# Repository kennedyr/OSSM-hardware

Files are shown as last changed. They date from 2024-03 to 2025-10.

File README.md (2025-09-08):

# OSSM - Open Source Sex Machine

OSSM Overview Image

### [**KinkyMakers Discord Community**](https://discord.gg/VtZcudpxT6) 
  
Most OSSM development takes place through ideas and CAD contributions made by enthusiastic discord members, join the discussion or show off your build!  

### Check out our docs at [GitBook](https://kinky-makers.gitbook.io/)

### [**Read the Frequently Asked Questions**](FAQ.md)

## **Summary**   
**OSSM** (pronounced like "awesome") is a user friendly every day sex machine for the people.

The OSSM's primary feature is that it is a servo powered belt-driven linear rail.  
This allows for quiet, high torque operation at speeds up to 1 meter per second, as well as for software-defined stroke and depth. 

**Standard Recommended Build at a glance**
 - 32 lbs (14 kg) of force @ 20v DC
   - Up to 50 lbs (22 kg) @ 36v DC
 - 8" Stroke (20 cm) with 350mm rail

This project aims to help people curious about sex machines explore their interest.   
A second objective is optionally learning how mechanics, electronics, physics and computing are involved in your sexual pleasure.

### **Primary** Design Goals
- Compact & quiet
- Highly performant
- Moderate cost
- 3D printable
- Easily-sourced components
- Moddable
  
<p align="center">

</p>

Note: This is a _work in progress_ and we have attempted to keep compatibility with the current BOM going
forward, but it's not guaranteed.

### Is it *actually* Open Source?
    CERN Open Hardware Licence Version 2 - Strongly Reciprocal
It is one of a kind Certified, Actual, Factual, Open Source  
[](https://certification.oshwa.org/ca000057.html)

Contributions to this GitHub repository assume the same license.

## **Safety**

The safety of the OSSM is yet to be fully characterized as it is a work in progress.  
The OSSM is a framework for building your own sex machine and as such your specific combination may have risks not inherent to other builds.  
**These risks may be undocumented or undiscovered. Please see the [Hazards](Documentation/Hazards.md) file for more information.**

Use of experimental/modified code increases the level of risk.

While using the OSSM we can suggest the following hierarchy of safety, however it is up to you and your build to decide
what risks exist and how to mitigate them.

1. Have ability to move away
2. Have ability to remove the power
3. If you are in bondage, safety is responsibility of the Top

## **Building Your OSSM**
### Motor Support  
 - 57AIM30 "Gold Motor" (Standard Recommended)
 - 42AIM30 "Round Motor" (Smaller form factor, limited mounting support)
 - iHSV57 "Legacy Motor" (Pre-2024 recommended motor)

The OSSM Software is written to support closed loop servo type motors and tested on the above motors.  
Most OSSM actuator and mounting hardware is designed for NEMA23 form factor motors.  
Attempting to use a stepper or other motor is not recommended; while it may be technically possible in some cases, this usually requires custom design work and advanced-level custom code. 

### Bill Of Materials for Standard Recommended Build

### Electronics  

 - Motor 
   - 57AIM30 ["Gold Motor"](https://www.researchanddesire.com/products/ossm-motor-gold-motor)
     - **Important note:** In order to operate with OSSM Software, motors must receive programming to set their "steps per revolution" to 800.
     - Motors from R+D are pre-programmed for OSSM. Motors from all other sources will need programming.
     - Programming requires a USB to 4 pin RS485 connector, cable for the 8 pin white motor plug, and use of the [Gold Motor Programming Tool](/Hardware/Servo%20Tools/Gold%20Motor/)
 - OSSM Reference Board, Remote, Wiring
    - [OSSM Reference PCB](https://www.researchanddesire.com/products/ossm-reference-board) or ESP32 Development Board
      - More information for board development [here](/Documentation/Board_Design.md).
    - [OSSM Remote](https://www.researchanddesire.com/products/ossm-reference-board)
    - JST-PH 2.0 4-Pin data cable and 16awg power wire
      - [Wire harness - Gold Motor](https://www.researchanddesire.com/products/ossm-wire-harness-gold-motor)
 - 20-36v DC Power Supply (5.5 x 2.1 Barrel Plug)
   - [24 volt 5 amp](https://www.researchanddesire.com/products/ossm-24v-power-supply) is recommended
   - Higher voltage, up to 36v, will provide increased force
   - USB Power Banks capable of true 100w USB PD also generally seem to operate well for a portable OSSM
     - [TESTED: ✓] INIU Power Bank P63-E1 100w (Old model: B63)
     - [TESTED: Powers down on high load] INIU B62 Power Bank 65W

### [**Printed Parts**](Printed%20Parts/) 
 - [Actuator](Printed%20Parts/Actuator/)
   - Body
   - Belt Tensioner
   - Threaded End Effector, Clamp + Nut  
 - [Remote](Printed%20Parts/Remote/)
   - Body
   - Knobs
 - [Toy Mounting](Printed%20Parts/Toy%20Mounting/)
   - Flange Base Plate with Clamping Ring (Tie-Down or Suction)
   - Double Double (Vac-U-Lock)
 - [Mounting](Printed%20Parts/Mounting/)
   - Mounting Ring (PitClamp Mini Ring)
   - Base (PitClamp Mini Base)
   - PCB Enclosure
 - [Stand](Printed%20Parts/Stand/)
   - 3030 Extrusion Base

Experimental parts pop up in the [KinkyMakers Discord](https://discord.gg/wrENMKb3) #ossm-print-testing channel.  
W.I.P. for the top rated to be merged into this repo.

### Standard Actuator Hardware
**GT2 Pulley** 

    (Qty 1) 8mm Bore, 20 Tooth, 10mm Width
**GT2 Timing Belt** 

    (Qty 1) 10mm Width, 500mm length
**MGN12H Rail + Bearing Block**

    (Qty 1)
    Minimum 250mm
    Suggested 350mm
    Maximum 550mm

Rail length = desired maximum stroke + 180mm  
Must be MGN**12H** rail.  
H is a longer bearing block than C for greater stability. 12 indicates 12mm rail width.

**Ball Bearings**

    (Qty 6) MR115-2RS 5x11x4mm 

**Fasteners**  

    (Qty 8) M3x8  Socket Cap Head Bolt 
    (Qty 2) M3x16 Socket Cap Head Bolt 
    (Qty 1) M3x20 Socket Cap Head Bolt 
    (Qty 7) M3 Hex Nut
    (Qty 3) M5x20 Socket Cap Head Bolt
    (Qty 1) M5 Hex Nut
    (Qty 4) M5x35 Socket Cap Head Bolt 
    (Qty 4) M5 20mm Hex Coupling Nut (Or M5 Hex Nut)

**Additional hardware is required for Stand, Mounting, Remote  
Detailed in their respective [Printed Parts](Printed%20Parts/) folder**

## Assembly

**Important note:** The actuator rail direction is critical for pattern accuracy and safety functions. The proper direction is with the threaded end to the right when looking at the front face of the actuator body - the "M" side of the OSSM text on the Cover.  
Outdated videos and documentation may show different directions. Your rail should extend the threaded end first when booted; if this does not match the behavior of your build you should reverse your rail's printed hardware.

  
### [**Build Instructions**](Documentation/Assembly%20Instructions.pdf)
(03.30.2025) Note: There have been recent improvements to the OSSM Standard Recommended build that are not yet reflected in this build document.  
Refer to exploded views from the Printed Parts folders for assembly of each major component.
## Build Videos

[OSSM Assembly Playlist](https://youtube.com/playlist?list=PLzSK7OAu3KNQsFo6WJGT8P28lfkD3xpps)

[OSSM Complete Assembly - Follow Along Guide](https://www.youtube.com/watch?v=9lVobSEw_Uw)

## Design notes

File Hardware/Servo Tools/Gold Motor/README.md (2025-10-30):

<h1> New Web Serial tool </h1>

Note programming an AIM motor requires not only power for the RS485, the motor needs between 20-40v otherwise it will not communicate. Look for the green light on the rear of the servo.  

in the "Javascript GMP" folder run the page in some browser that supports web serial and hopefully it'll just work. 



<h1> Old Python Script </h1>
This pyhton script will write the default changes to the gold motor and show all the current settings in mostly english



the settings we change by default are



Watch out, I got tired of using the tool provided by the vendor and this was done quickly one night with ChatGPT as my copilot...

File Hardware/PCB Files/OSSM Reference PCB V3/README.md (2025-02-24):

# OSSM V3 Board info

## V3 Changes

1. ESP32 -> ESP32-S3
2. Current monitor is changed from an analog monitor to an in-line resistor and the INA219.

## Beta 1 testing

1. Motor motion
    1. The U8g2 library doesn't play nice with other devices on the I2C bus. There are a few different things happening here.  First, the bus maxes out the clock speed per the display.  Second the code doesn't want to play nice with the buffers
1. General Connections
    1. The Encoder wheel's A/B lines are swapped. (Or somehow the encoder works backwards)
1. RS485 works-ish.
    1. Packets are being sent and recieved, but the motor is responding with a function code that isn't listed.
    1. The RE/DE pins should be shorted in HW.  (Probably using a solder jumper)
1. Neopixel Works with the FastLED library.
1. TODO: HUSB238 I2C connection. Not critical to check, but should be moved with INA219

### Beta1 -> RC1 Changes

1. Move display to it's own I2C periphal.
1. Change HUSB28 to HUSB238A.  It is available on LCSC and will allow higher power.
    1. Double check all components to handle max voltage.  Should that be 36V (Gold motor max) or 48V (IC max)
1. Make the programmable LED smaller
1. Swap Encoder A/B pins
1. Short the DE and RE pins
1. Shrink Q1&Q2
1. Pick final connectors for Motor connection (both power/pulse/dir and RS85)
1. Pick connector for remote
1. Change PCB form factor

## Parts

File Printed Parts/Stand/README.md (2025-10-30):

### Default base: [3030 Extrusion - Single Pivot Arm](#ossm---3030-extrusion-mount)

# OSSM - 3030 Extrusion Mount

<!-- ### [Bill Of Materials](3030%20Extrusion%20Base/BOM.md)   -->

### [Assembly Guide Videos](https://www.youtube.com/playlist?list=PLzSK7OAu3KNS-aOQfpv3f_BJH9GNdLJ7Q)

### Printing

**3030 Extrusion Mount Standard Print Settings:**

    6 Walls
    Infill type: Cross Hatch (or gyroid) 25%
    Supports: None

- **Filament estimate:** 246g
- **Recommended filament:** PLA+
- All parts are intended to print in the provided file default orientation.

**Printed parts:**

    (Qty 1) Pivot Plate Left
    (Qty 1) Pivot Plate Right
    (Qty 8) Handle Spacer
    (Qty 4) Extrusion Foot
    (Qty 6) Extrusion Cap

<!-- ### [Additional Documentation](3030%20Extrusion%20Base/README.md)  -->

### Bill Of Materials

    (Qty 12) M6x12 Socket Cap Head Bolt
    (Qty  6) M6x25 Socket Cap Head Bolt
    (Qty  2) M6 Handle 25mm
    (Qty  6) M6 Washer
    (Qty 20) M6 T-Nut '3030'
    (Qty  4) 90 Degree '3030' Corner Bracket
    (Qty  2) 1.5" (38mm) Reinforced Rubber Washer
    (Qty  4) 1.5" (38mm) Square Non-Slip Furniture Pad
    (Qty  1) 20" (508mm) 3030 Extrusion
    (Qty  1) 18" (467mm) 3030 Extrusion
    (Qty  2) 14" (355mm) 3030 Extrusion
    (Recommended) Sandbag

## Legacy README

The above BOM is accurate for a new Stand-only assembly. Actuator and PCB Mounting BOM can be found in [Mounting](/Printed%20Parts/Mounting/)

Legacy README retained for Stand assembly reference

    //TODO: Needs update for 57AIM30 Gold Motor & PitClamp Mini default build.

You can view the 3D model at
[OnShape link](https://cad.onshape.com/documents/d520ea9a8cadb4ae8681f59b/w/00b211a6fa3b76c59ef28f4e/e/5f2c80d9d9c2433a7be7f789)



<!-- ![image](https://github.com/KinkyMakers/OSSM-hardware/assets/12459679/68e3e564-df99-465a-8d91-f74ca8b0cc89) -->



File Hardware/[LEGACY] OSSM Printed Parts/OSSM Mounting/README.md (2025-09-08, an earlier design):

# Mounting Options

There are several options for mounting your OSSM! You will find descriptions of the mounts below, and the files and instructions on how to build them in the folders above. 

The **OSSM Basic Mount** is the "official" design and is available to [purchase from Research and Desire](https://shop.researchanddesire.com/collections/all/products/ossm-basic-mount). It is mostly 3D printed and is screwed down to a piece of wood, furniture, shelf etc. It uses the 3D printed middle pivot and threaded handles. Current design relies on sourcing a length of 3030 extrusion (1.5" will also work). This is one of the less expensive options. Picture below.

rdmount

The **Shicks 4040 mount** was created by discord community member Shicks101 (Thanks!) and is made out of Aluminum Extrusion and 3D printed parts. It supports a high level of articulation and variability in height. The parts are easy to get, but it is a little more costly. You may need to weigh it down with dumbbells or sandbags. Picture below.

resized

The **OSSM Extrusion Mount** is an extrusion based mount that is simple to print and assemble requiring no cutting tools if you can get extrusion at the correct length. It uses the standard middle pivot and only a few 3D printed pieces.


**Emma's mod** is for the use of a long Nema23. This mount is mostly 3D printed and was created for a different machine, but will still work. (no photo available)  

There are a few more mounting options created by community members in the Discord that are not present here in the repository. Some are motorized! Or if none of these fit your use case, you could create your own and share it with the community.

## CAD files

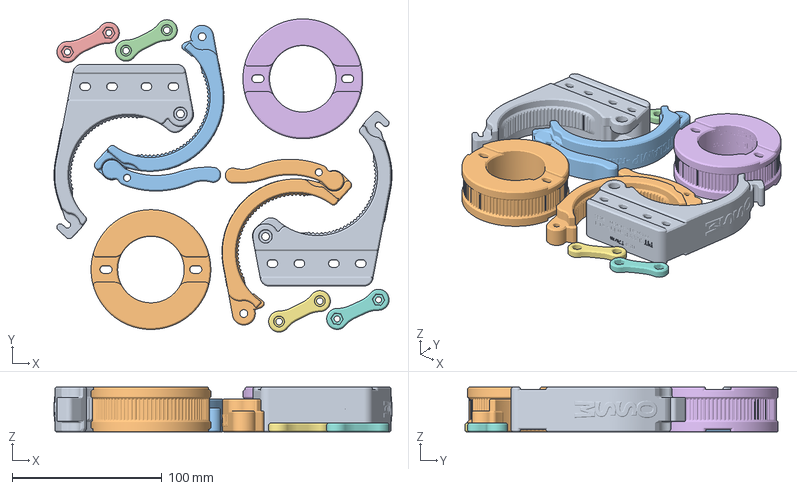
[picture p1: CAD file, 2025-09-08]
Printed Parts/OSSM Mods/PitClamp Mini Reinforced 3030 Hinges/Preconfigured 3mf/[Generic_3mf] 2x - PitClamp Mini v1.1 - Reinforced 3030 Hinge Complete.3mf
225.9 x 209.2 x 30.0 mm
OSSM - Base - PitClamp Mini - Lower V1.1 - Reinforced SideMount 3030.stl x 2
OSSM - Mounting Ring - PitClamp Mini - Extrusion Reinforced.stl x 2
OSSM - Base - PitClamp Mini - Upper V1.1 + Handle (Print In Place).stp x 2
OSSM - Base - PitClamp Mini - Dogbone Bolts.stp x 2
OSSM - Base - PitClamp Mini - Dogbone Nuts.stp x 2

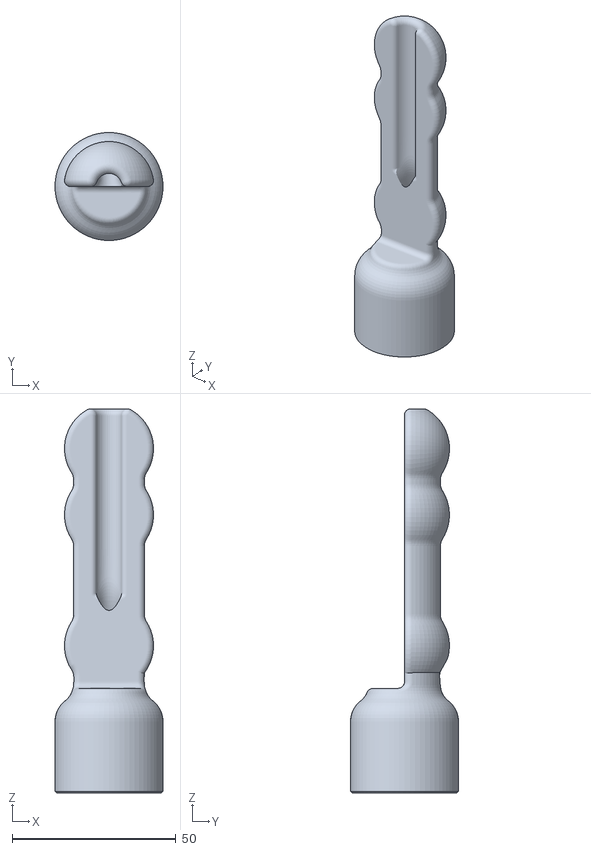
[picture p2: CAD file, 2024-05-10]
Hardware/OSSM Printed Parts/end effector options/Silly/OSSM hold random object on 24mm thread.stl
33.0 x 33.0 x 117.4

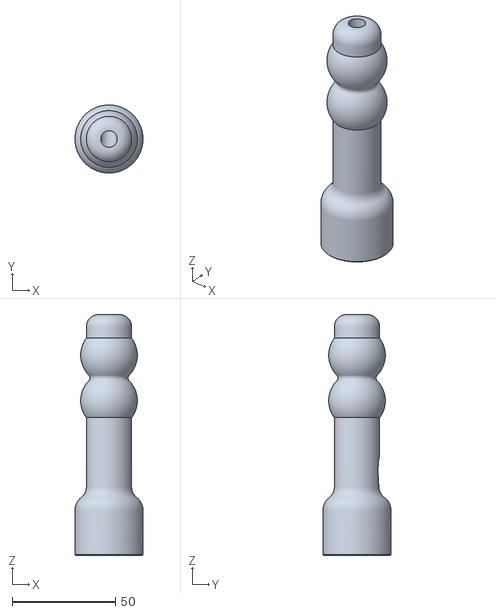
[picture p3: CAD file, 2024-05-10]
Hardware/OSSM Printed Parts/OSSM - Toy mount - Dildo mount Double Double (vac-u-loc)- 24mm threaded.stl
33.0 x 33.0 x 116.8

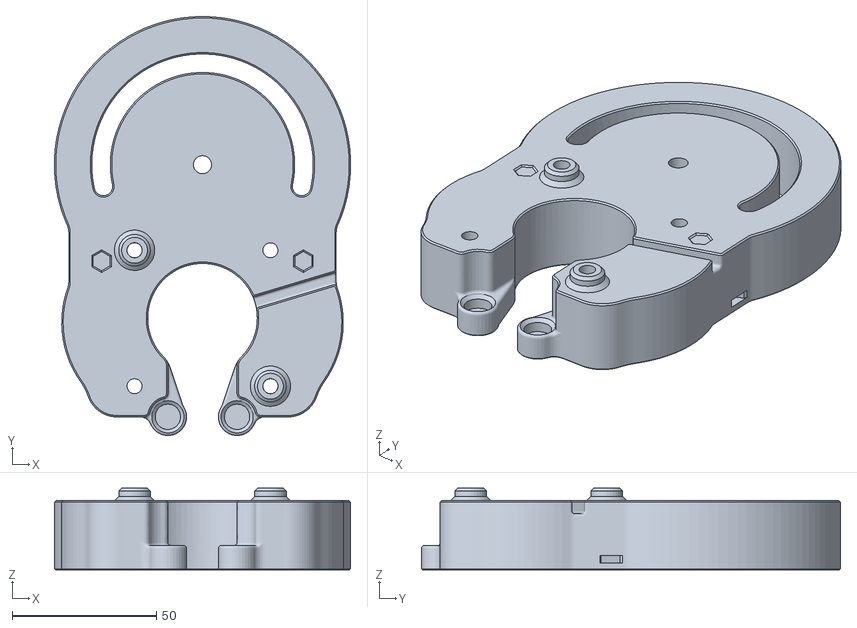
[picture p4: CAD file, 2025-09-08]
Printed Parts/Actuator/Non-standard/OSSM - Actuator - Body - Middle Pivot.stl
102.8 x 145.3 x 28.4

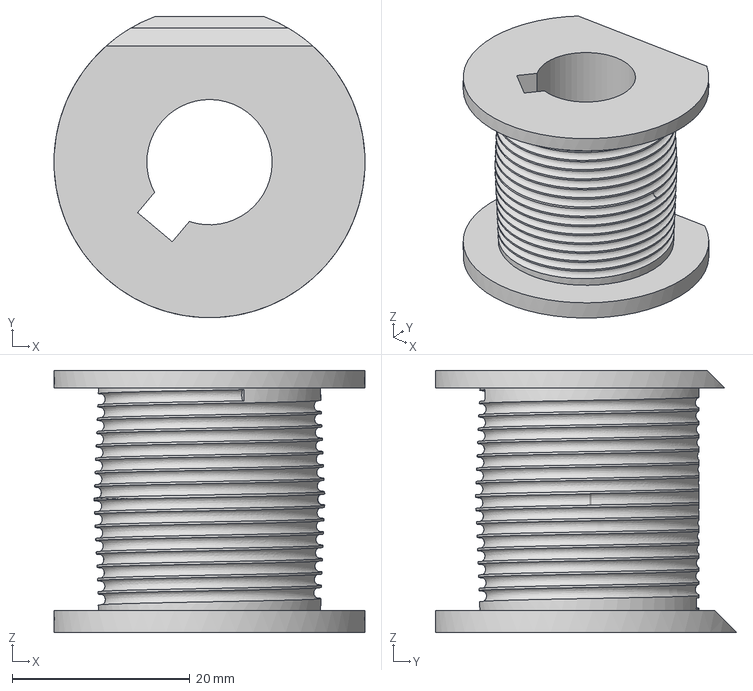
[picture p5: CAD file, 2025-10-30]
Printed Parts/OSSM Mods/SaladDressing's Mods/Capstan OSSM XL/Hardware/.step/CapstanPulley60AIM25.step
35.0 x 33.9 x 29.5 mm

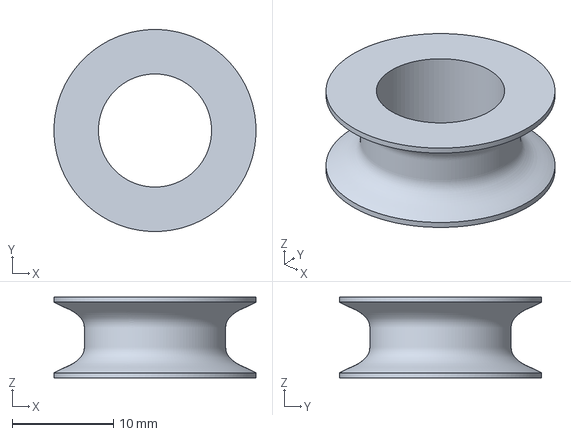
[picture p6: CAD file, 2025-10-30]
Printed Parts/OSSM Mods/SaladDressing's Mods/Capstan OSSM XL/Hardware/3D printed parts/8mmEndPulley.3mf
20.0 x 20.0 x 8.00 mm

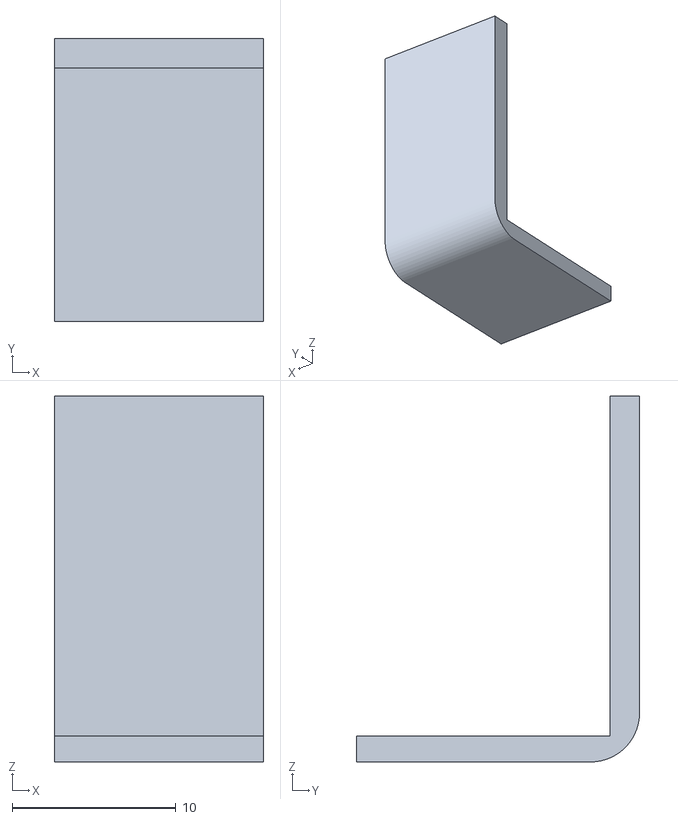
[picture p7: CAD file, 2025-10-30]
Printed Parts/OSSM Mods/SaladDressing's Mods/Capstan OSSM XL/Hardware/3D printed parts/AIO Mod (recommended)/Standoff2.stl
12.8 x 17.3 x 22.4

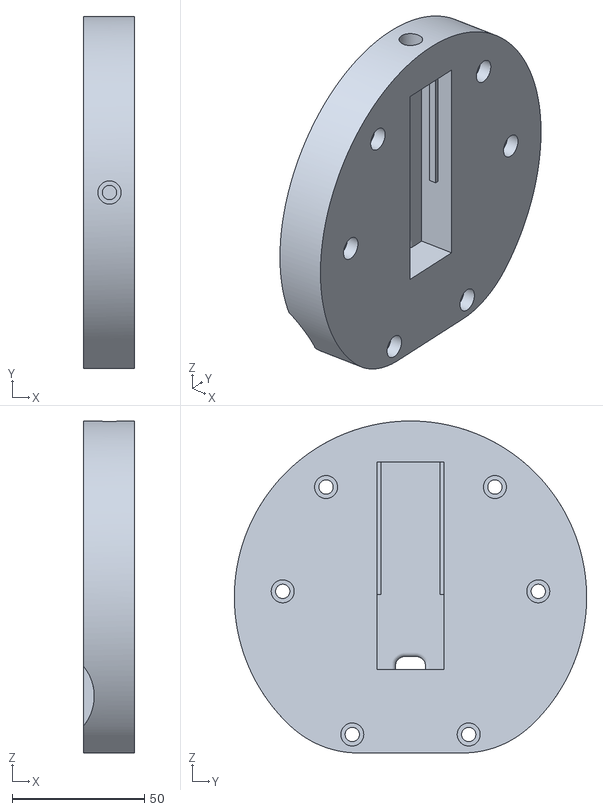
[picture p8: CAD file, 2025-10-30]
Printed Parts/OSSM Mods/SaladDressing's Mods/Capstan OSSM XL/Hardware/3D printed parts/Normal (for customized PCB Mounting)/MotorHeadFront.stl
19.1 x 133.1 x 125.5

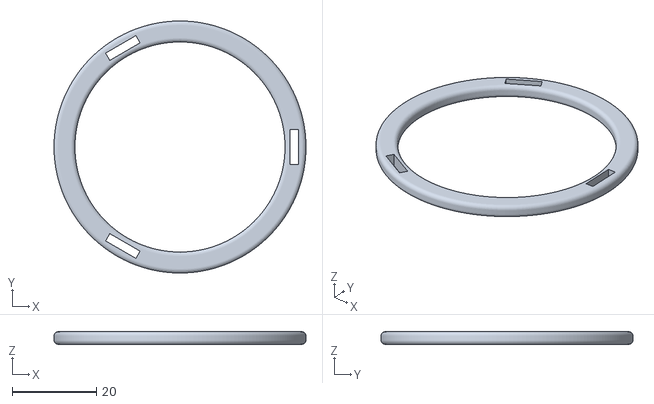
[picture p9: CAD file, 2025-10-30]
Printed Parts/OSSM Mods/SaladDressing's Mods/Quick Change Strap Toy Mount Remix/Ring50mm.stl
60.0 x 60.0 x 3.00

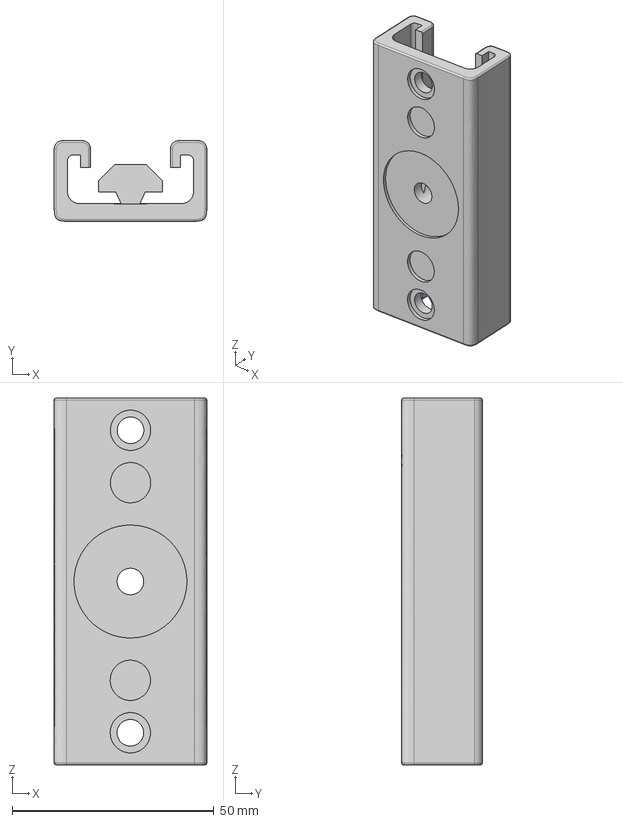
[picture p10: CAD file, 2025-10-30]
Printed Parts/OSSM Mods/SaladDressing's Mods/Suction Cup Bracket/SuctionCupBracket - 3030 Amazon by neos.step
37.8 x 20.0 x 91.0 mm

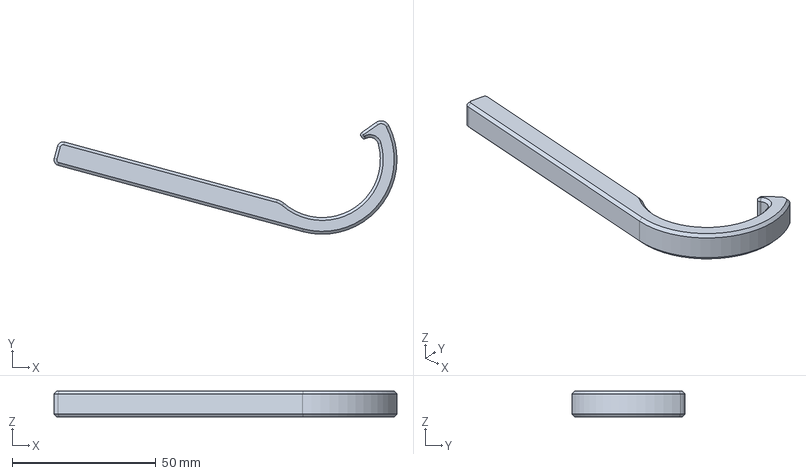
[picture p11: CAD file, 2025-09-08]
Printed Parts/OSSM Mods/Threaded Belt Clamp V2/STEP/Tool - Hex Flower Wrench.stp
119.2 x 39.4 x 9.00 mm

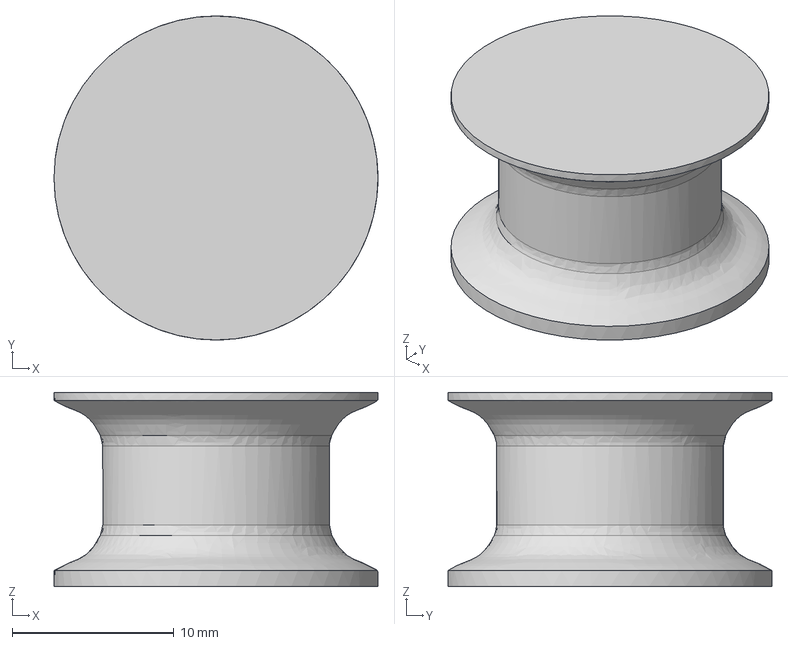
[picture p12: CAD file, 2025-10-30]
Printed Parts/OSSM Mods/SaladDressing's Mods/Capstan OSSM XL/Hardware/.step/EndPulley12mm.step
20.0 x 20.0 x 12.0 mm

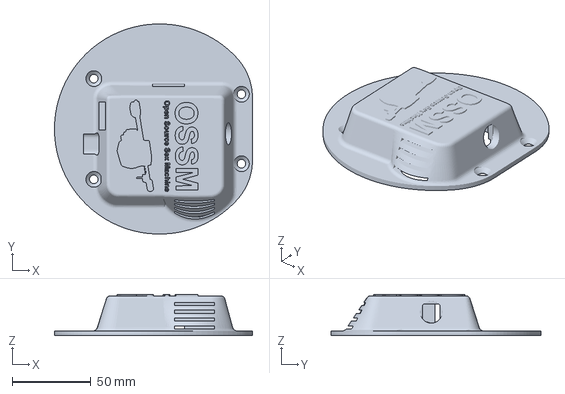
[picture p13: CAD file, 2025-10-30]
Printed Parts/OSSM Mods/SaladDressing's Mods/Capstan OSSM XL/Hardware/3D printed parts/AIO Mod (recommended)/AIO_Cover.3mf
125.4 x 133.1 x 26.2 mm

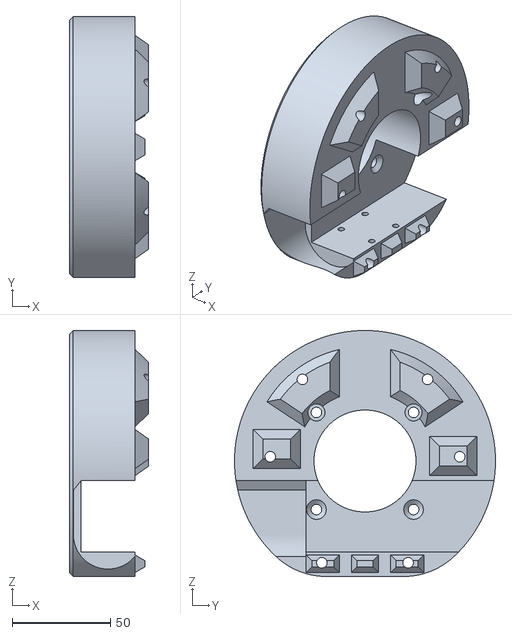
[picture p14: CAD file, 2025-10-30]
Printed Parts/OSSM Mods/SaladDressing's Mods/Capstan OSSM XL/Hardware/3D printed parts/Normal (for customized PCB Mounting)/MotorHeadBack.stl
40.5 x 133.1 x 125.5

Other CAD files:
Printed Parts/OSSM Mods/SaladDressing's Mods/Capstan OSSM XL/Hardware/3D printed parts/TensionerLower.stl
Printed Parts/OSSM Mods/SaladDressing's Mods/Quick Change Strap Toy Mount Remix/universal_strap_3mm_notch.stl
Printed Parts/OSSM Mods/SaladDressing's Mods/Suction Cup Bracket/SuctionCupBracket - 4040 Aluxprofile.step
Printed Parts/OSSM Mods/SaladDressing's Mods/Weight Plate Bracket/Weight Plate Bracket Olympic.step
Hardware/[LEGACY] OSSM Printed Parts/OSSM Mounting/Deprecated - Ball Head Mount/Fusion Files/Adjustable arm for ball head mount v2.f3d
Hardware/[LEGACY] OSSM Printed Parts/OSSM Mounting/Deprecated - Ball Head Mount/STL Files/Extension arm for ball head.stl
Hardware/[LEGACY] OSSM Printed Parts/OSSM Mounting/Deprecated - Ball Head Mount/STL Files/Mounting base left side.stl
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

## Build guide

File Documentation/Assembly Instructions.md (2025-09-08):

# Assembly Instructions

#### _Note: This file is a work in progress migration of legacy documentation and may contain outdated information or parts_

## Open Source Sex Machine

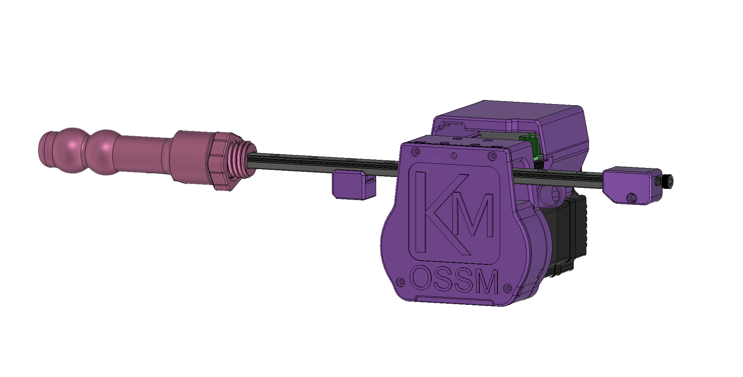
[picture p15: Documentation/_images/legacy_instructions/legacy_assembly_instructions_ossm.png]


Assembly Guide

### Table of Contents

* [Some comments on Safety](<Assembly Instructions.md#some-comments-on-safety>)
* [Parts Checklist](<Assembly Instructions.md#parts-checklist>)
  * [Purchased Parts](<Assembly Instructions.md#purchased-parts>)
  * [Printed Parts](<Assembly Instructions.md#printed-parts>)
* [Assembly Instructions](<Assembly Instructions.md#assembly-instructions>)
  * [Mate the Base Plate with the Motor](<Assembly Instructions.md#mate-the-base-plate-with-the-motor>)
  * [Build up the belt idler bearings](<Assembly Instructions.md#build-up-the-belt-idler-bearings>)
  * [Install and Align the Pulley](<Assembly Instructions.md#install-and-align-the-pulley>)
  * [Linear Rail Installation](<Assembly Instructions.md#linear-rail-installation>)
  * [Alternate Middle – Pivot](<Assembly Instructions.md#alternate-middle--pivot>)
  * [Belt Placement](<Assembly Instructions.md#belt-placement>)
  * [Belt Tensioner](<Assembly Instructions.md#belt-tensioner>)
  * [Wrap Belt Around Pulley](<Assembly Instructions.md#wrap-belt-around-pulley>)
  * [Belt Clamp](<Assembly Instructions.md#belt-clamp>)

## Some comments on Safety

### General Safety

* We’ve worked to make building an OSSM easy and not require expert level knowledge. With that said, only you can be responsible for your safety. If you are unsure about something, find a resource, ask the discord, or just pause for a minute before rushing into it. This is a DIY project, and everyone’s build is a bit different – so make sure you are comfortable with your setup and understand how it works!

### Electrical Safety

* 24V is generally considered a fairly safe, low voltage, but always be careful to check wiring polarity and make sure nothing conductive is near the board or power supply that could cause a short circuit.

### Mechanical Safety

* There are some pinch points in the OSSM near the rail – keep sensitive bits away from that during use!
* Depending on your motor selection, the OSSM can generate quite a bit of force, and that can hurt if it’s not applied in the right way, especially in delicate orifices! Always be able to move away from the machine if needed, or have someone specifically responsible for your safety if using it with a partner. Everyone has their own level or risk tolerance, so make sure you understand how your setup works, and give consideration to what you would do should something go wrong.

\
\
This is an open-source, community based project. Lots of people contribute to its success which is a huge strength for developing quickly! It also means we are not responsible for the complete safety of the design. Play risk-aware and consensually!\

## Parts Checklist

The Github list is always to be considered to be more up-to-date than this document, if there are discrepancies please visit the Discord and ask for clarification in #OSSM

This guide is for the complete OFFICAL OSSM, however there are many modifications that you may choose to make for your specific build.

### Purchased Parts

| | |
| --- | --- |
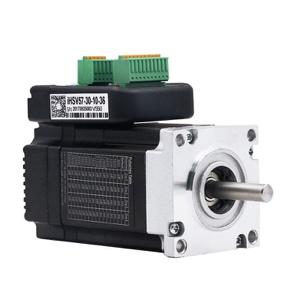
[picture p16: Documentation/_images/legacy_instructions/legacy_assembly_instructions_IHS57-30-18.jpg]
| **Nema 23 Servo Motor – IHSV57-30-18** Most people choose the 180W model for max power. 140 and 100w are also available. Avoid the _StepperOnline_ version because of compatibility issues |  |
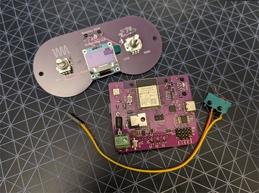
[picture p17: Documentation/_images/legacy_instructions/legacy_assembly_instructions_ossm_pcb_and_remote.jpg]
| **OSSM PCB & Remote** |  |
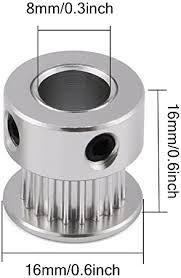
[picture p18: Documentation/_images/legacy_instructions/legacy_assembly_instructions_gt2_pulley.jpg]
| **GT2 Pulley – 20 Tooth, 8mm Bore, 10mm belt** |  |
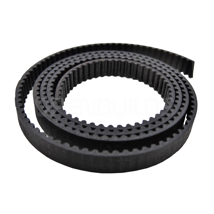
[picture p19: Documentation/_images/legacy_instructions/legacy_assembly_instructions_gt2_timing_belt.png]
| **GT2 Timing Belt – 10mm Width x 500mm length** Get a bulk amount of belt 500mm is a minimum for a standard build |  |
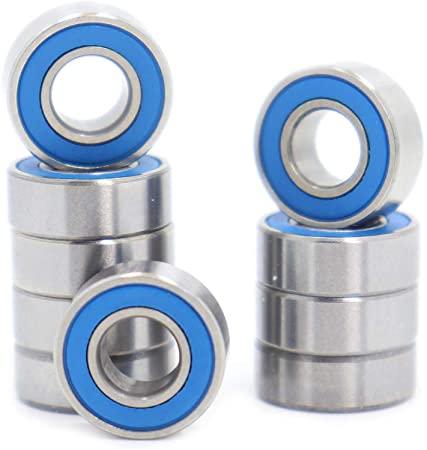
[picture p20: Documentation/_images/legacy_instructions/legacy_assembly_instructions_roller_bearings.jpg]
| **Roller Bearings MR115 – 5x11x4mm (Qty:6)** |  |
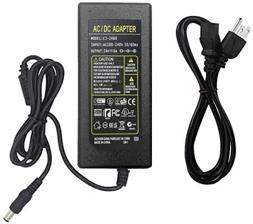
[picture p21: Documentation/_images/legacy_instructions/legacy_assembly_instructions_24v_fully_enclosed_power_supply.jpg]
| **24v 5A fully enclosed power supply** Look for one that is certified for use in your country |  |
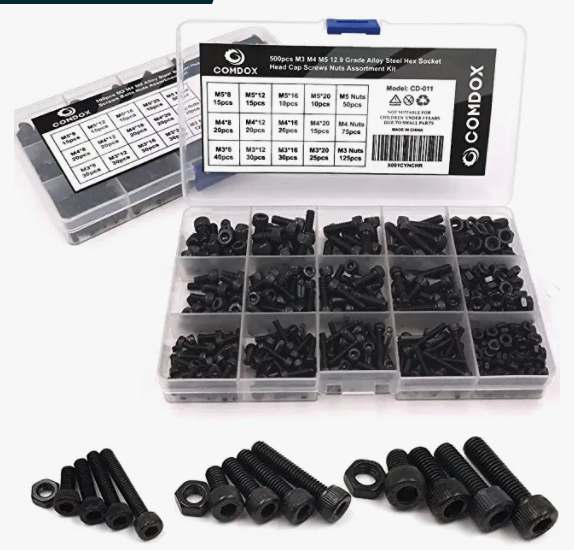
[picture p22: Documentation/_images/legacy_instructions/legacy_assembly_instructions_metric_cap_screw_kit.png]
| Metric Cap Screw Kit Should be about $20 USD, M5, M4, and M3 are used in the build in various lengths Most M5 cap head screws are 20/25mm long The Middle Pivot mount requires 4x m5x35 screws |  |
| | |

### Printed Parts

| | |
| :---: | --- |
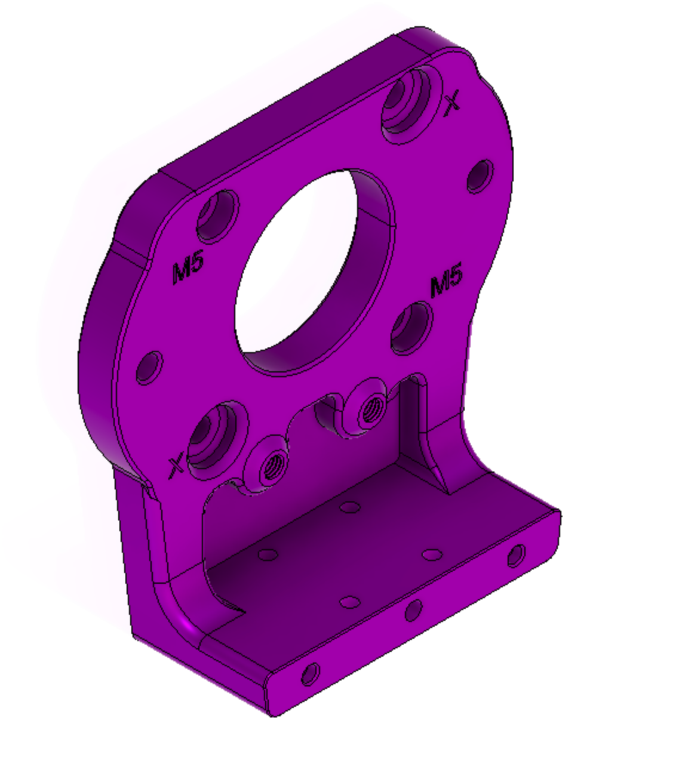
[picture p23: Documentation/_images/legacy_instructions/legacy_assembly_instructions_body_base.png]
| **Body - Base** |  |
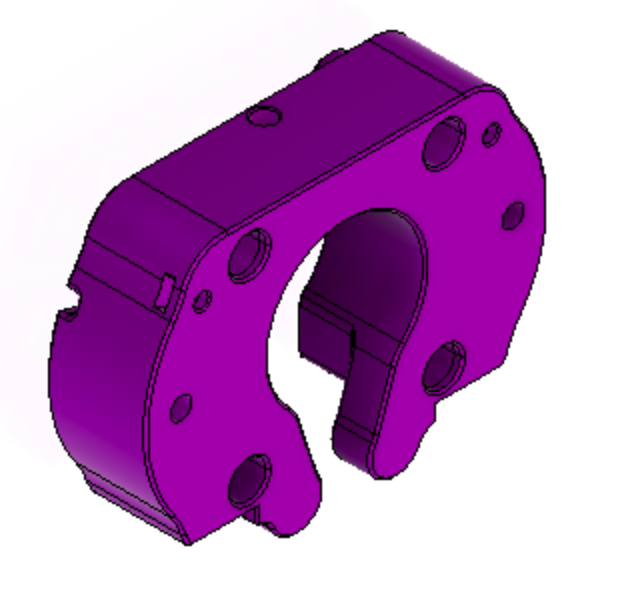
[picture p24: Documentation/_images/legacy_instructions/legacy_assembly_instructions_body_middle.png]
| **Body - Middle** |  |
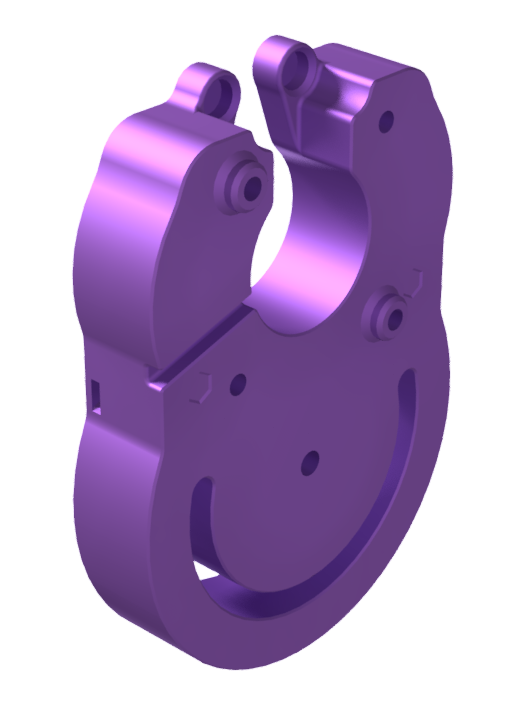
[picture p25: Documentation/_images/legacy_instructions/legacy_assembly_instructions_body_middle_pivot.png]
| **Body – Middle Pivot (Use instead for more mounting options)** |  |
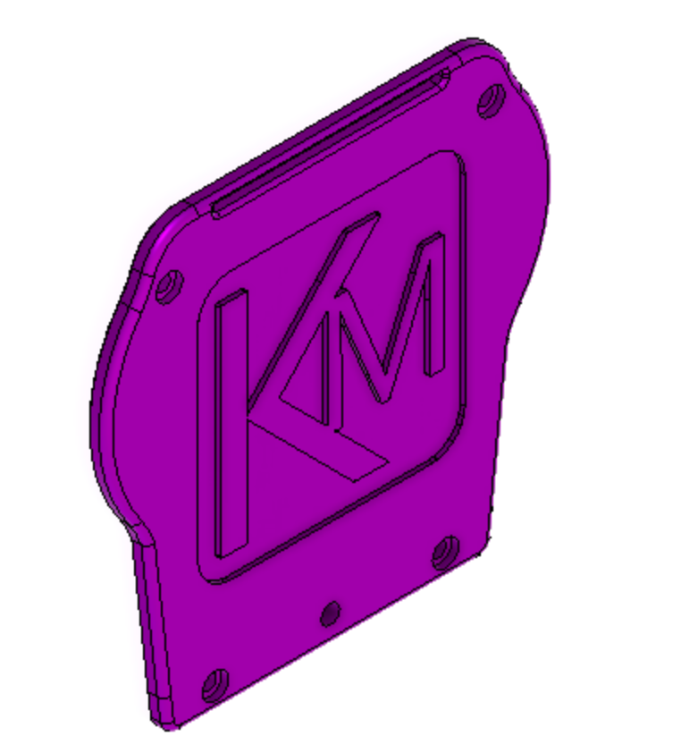
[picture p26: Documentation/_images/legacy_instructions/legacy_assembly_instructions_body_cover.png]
| **Body - Cover** |  |
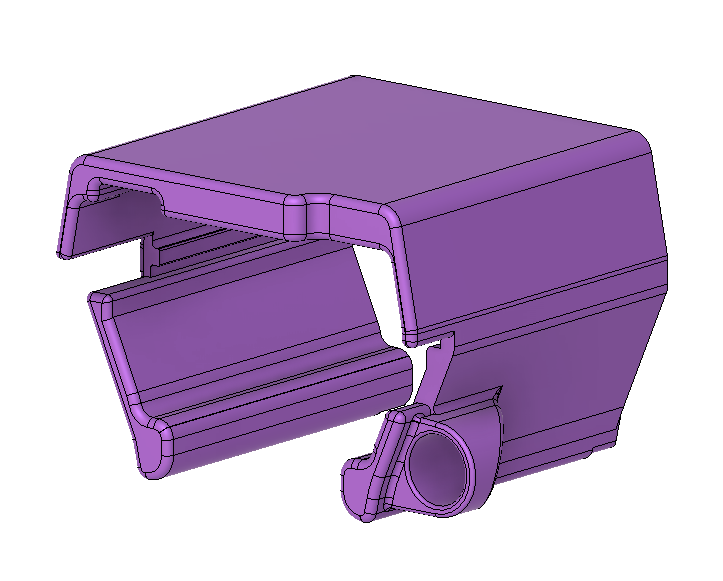
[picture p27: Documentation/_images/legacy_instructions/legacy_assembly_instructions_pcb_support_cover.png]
| **Body - PCB Support Cover** |  |
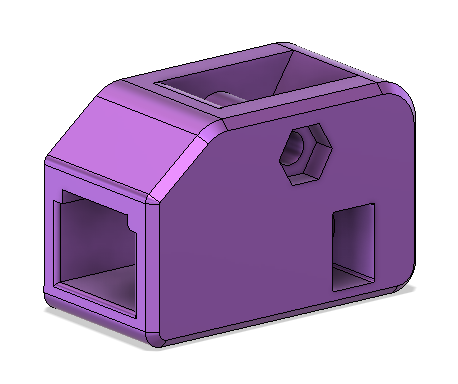
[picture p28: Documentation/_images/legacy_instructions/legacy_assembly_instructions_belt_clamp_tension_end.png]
| **Belt Clamp – Tensioner end** |  |
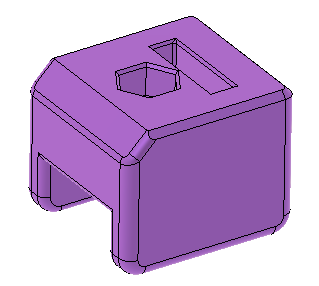
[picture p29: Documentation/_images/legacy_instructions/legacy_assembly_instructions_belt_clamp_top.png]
| **Belt Clamp - Top** |  |
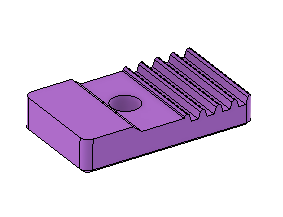
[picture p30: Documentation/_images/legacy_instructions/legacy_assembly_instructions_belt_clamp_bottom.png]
| **Belt Clamp - Bottom** |  |
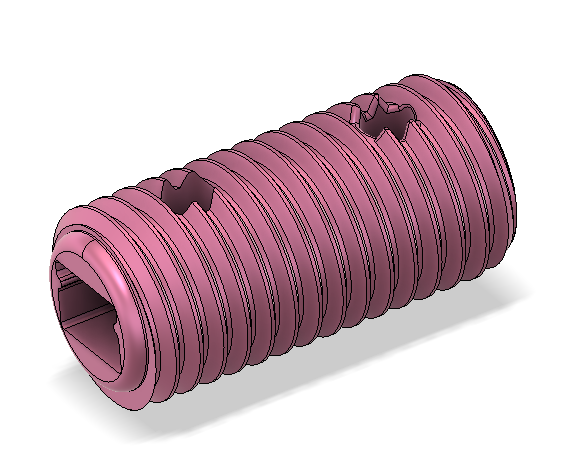
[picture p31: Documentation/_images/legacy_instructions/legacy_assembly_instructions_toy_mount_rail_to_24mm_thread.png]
| **Toy Mount – Rail to 24mm thread** |  |
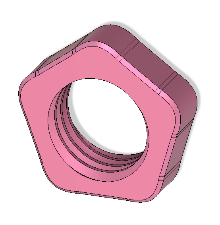
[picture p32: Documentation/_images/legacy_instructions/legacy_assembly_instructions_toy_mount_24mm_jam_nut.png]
| **Toy Mount - 24MM Jam Nut** |  |
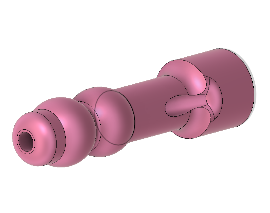
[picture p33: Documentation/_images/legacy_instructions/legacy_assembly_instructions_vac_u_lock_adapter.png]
| **Toy Mount - Vac-u-lock adapter (double double)** |  |
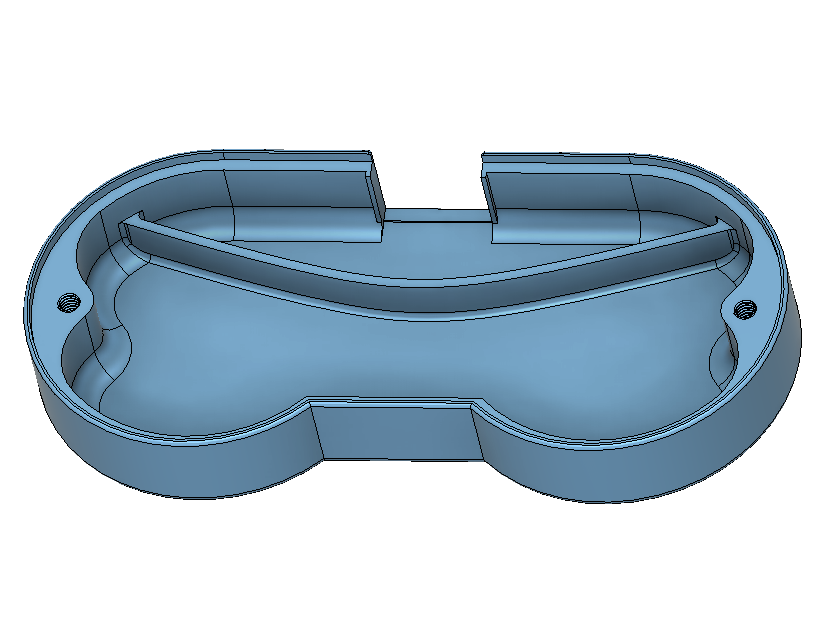
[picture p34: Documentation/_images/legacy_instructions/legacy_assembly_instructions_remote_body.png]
| **Remote Body** |  |
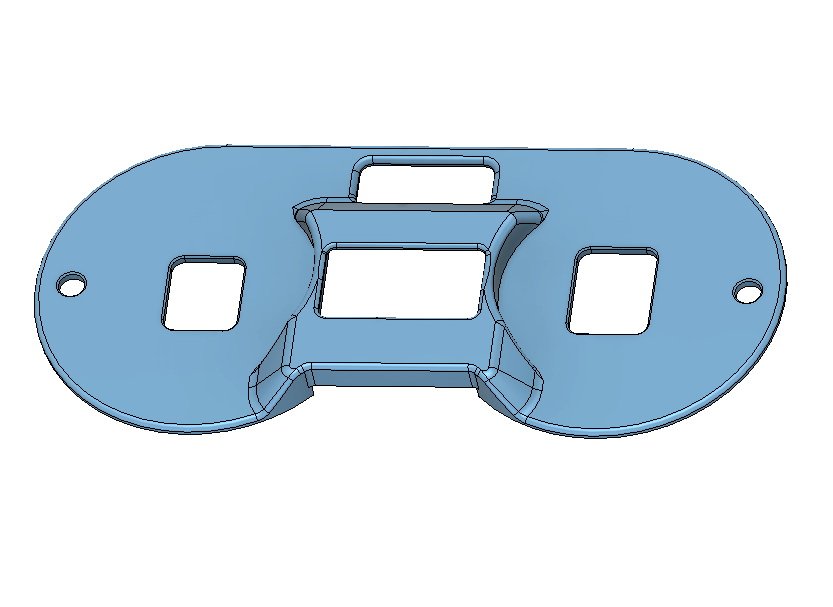
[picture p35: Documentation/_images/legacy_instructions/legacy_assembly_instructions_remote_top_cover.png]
| **Remote Top Cover** |  |
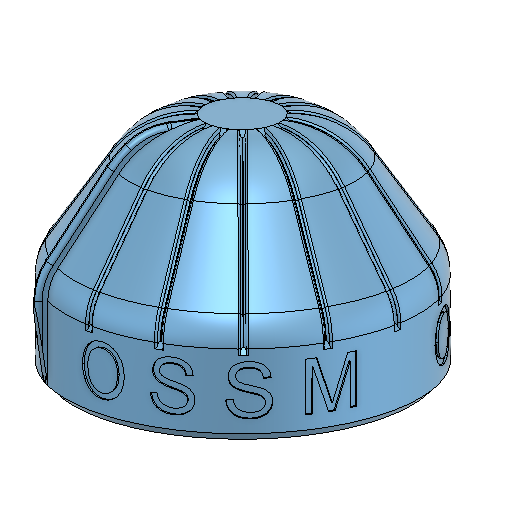
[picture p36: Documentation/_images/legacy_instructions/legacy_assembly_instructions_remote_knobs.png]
| **Remote Knobs x 2** |  |
| | |

\
\
\

## Assembly Instructions

\

### General Assembly Comments

#### Threadlocker

Recommend you use some form of threadlocker/Loctite on the fasteners going into metal (nuts of bearing) to prevent them from loosening as the ossm gets shaken around quite a bit.

If you do not have Loctite, some plain white glue does a decent job, just a small amount on the ends of the threads is all you need.

You can also put threadlocker on the motor shaft to help keep the pulley tightly in place – just be sure you are happy with it’s position, this can be very hard to remove!

#### Assembly Videos

We now have a full set of videos showing the assembly process linked on the github main page, and at ossm.tech You can also find links to online CAD models to help see how things go together!

### Mate the Base Plate with the Motor

Attach the OSSM base plate to the motor with (2) 5x20mm cap head screws in the locations marked _M5_ and tighten with a M5 nut below the motor mounting flange. The nut is usually kept from turning by the motor body. If it spins when tightening, insert a flat head screwdriver between the nut and motor to keep it in place.

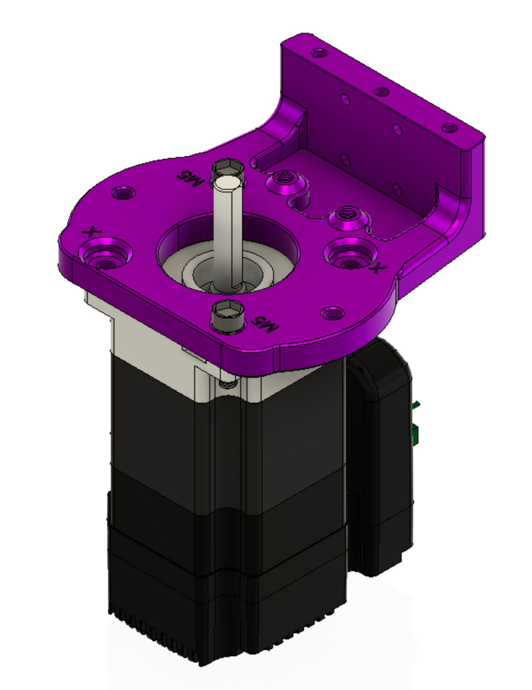
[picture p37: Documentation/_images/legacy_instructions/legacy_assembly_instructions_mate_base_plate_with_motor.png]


### Build up the belt idler bearings

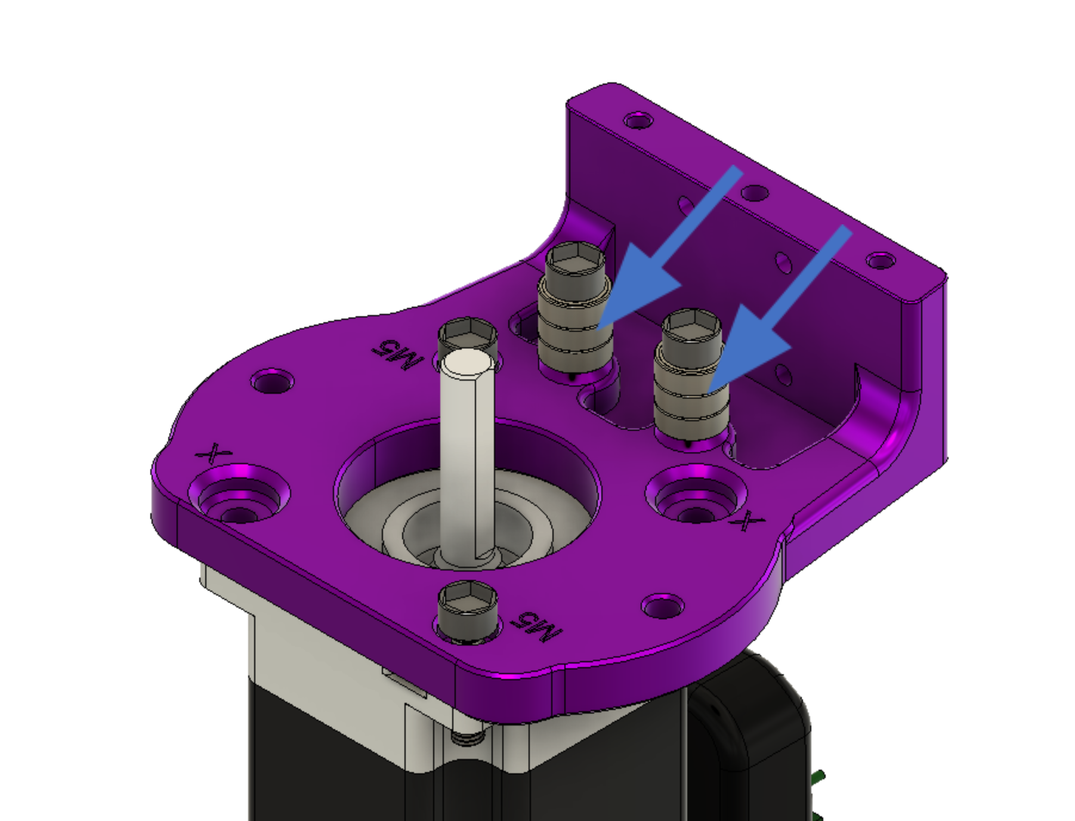
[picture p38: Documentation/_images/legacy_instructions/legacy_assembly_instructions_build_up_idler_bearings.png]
build\_up\_idler\_bearings
\

The idler bearing stacks are built up around 5x20mm cap head screw\
\
Stack three 5x11x4mm bearings on a 5x20mm cap head screw and attach to the threaded positions in the baseplate as shown above.

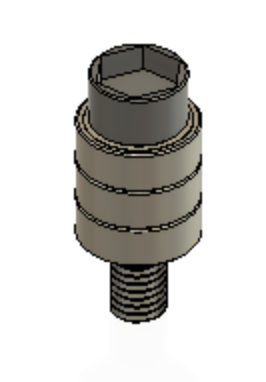
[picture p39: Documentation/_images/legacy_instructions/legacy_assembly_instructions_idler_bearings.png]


### Install and Align the Pulley

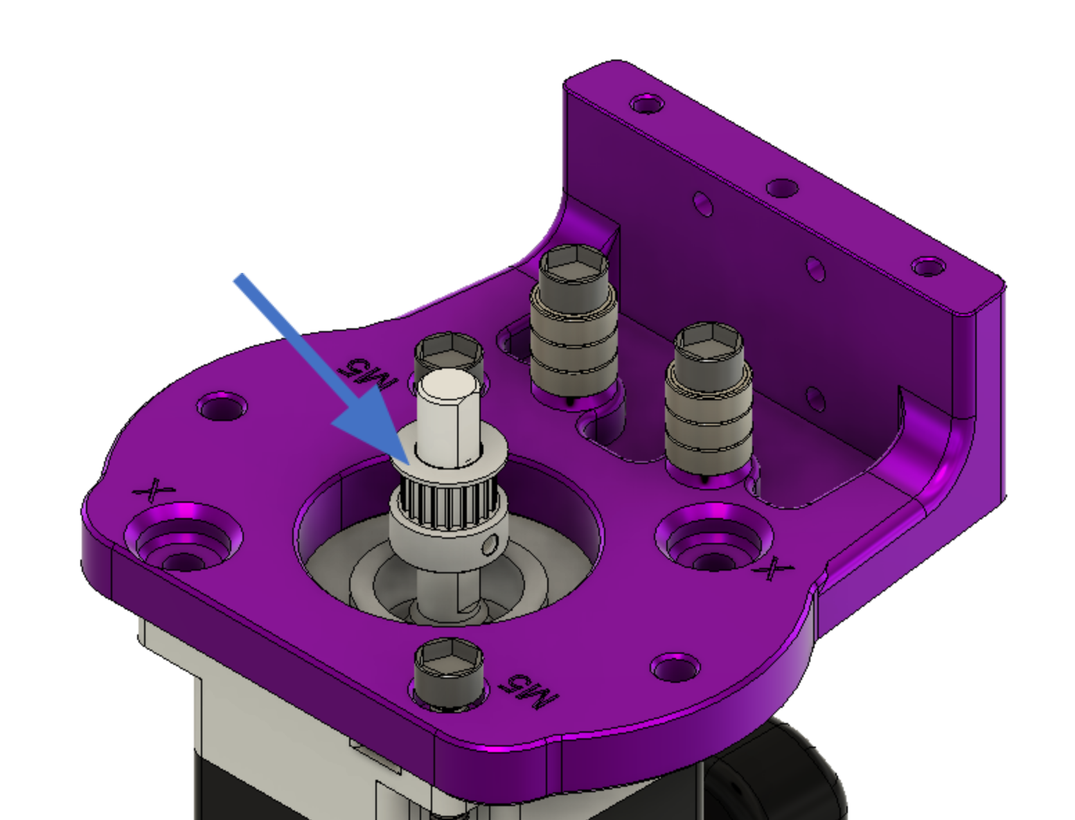
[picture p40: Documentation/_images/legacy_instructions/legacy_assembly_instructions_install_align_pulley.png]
install\_align\_pulley


* Mount the 20 tooth GT2 Pulley on the shaft of the motor
* Make sure you line up one of the set screws with the flat on the motor!

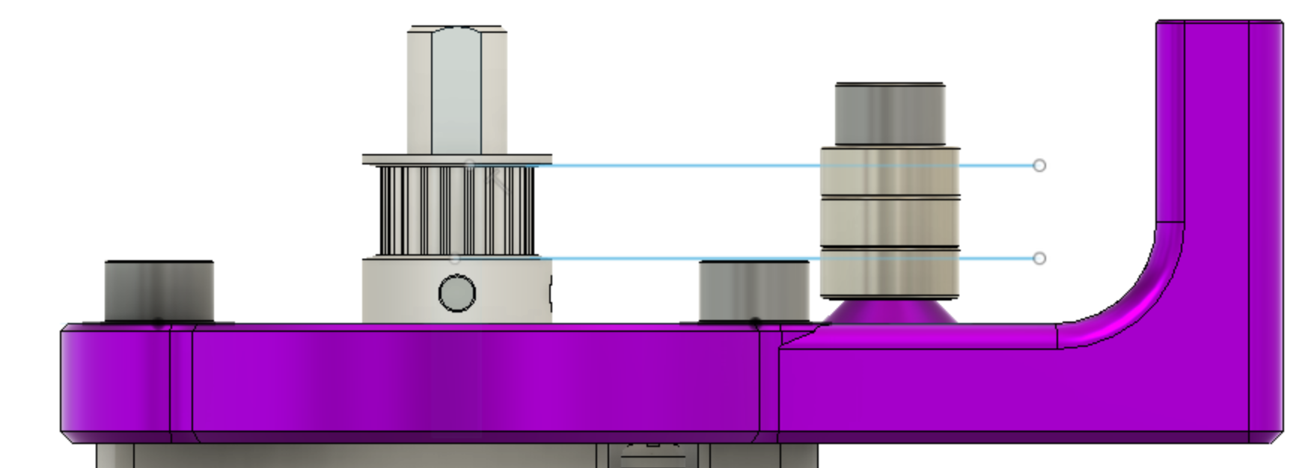
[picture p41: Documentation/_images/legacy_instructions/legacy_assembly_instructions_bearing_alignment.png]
\

### Linear Rail Installation

Align the pulley so that it is within the range of the bearings and the set screws that clamp it to the motor shaft are available from above the base plate

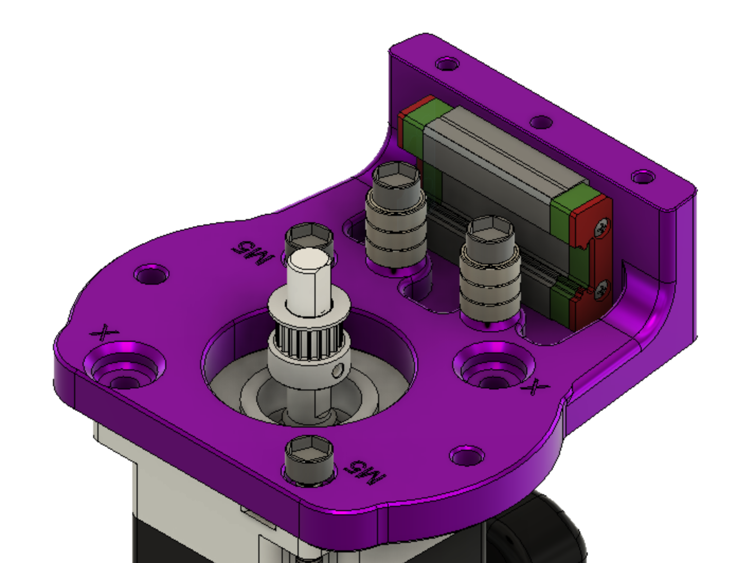
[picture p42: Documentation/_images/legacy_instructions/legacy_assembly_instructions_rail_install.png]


MGNRH Rail and Bearing are next. _linear rail is omitted from this view._

\
\

**Be careful not to separate bearing from linear rail, there is a chance of losing ball bearings when the rail and bearing are separated!**\
\

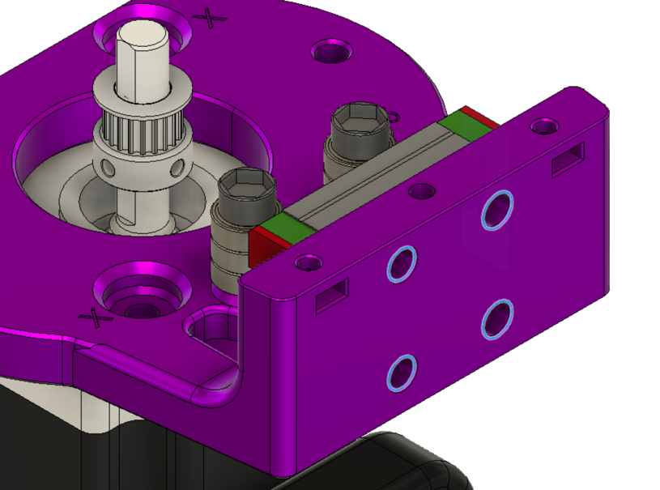
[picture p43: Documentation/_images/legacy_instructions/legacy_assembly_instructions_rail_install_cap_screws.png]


Highlighted holes for M3 cap screws. The cap screws should finish flush with surface when fully tightened.

\
\
\

Attach the middle part of the OSSM body utilizing the remaining diagonal holes. The M5x20mm shown below being inserted into the correct positions.

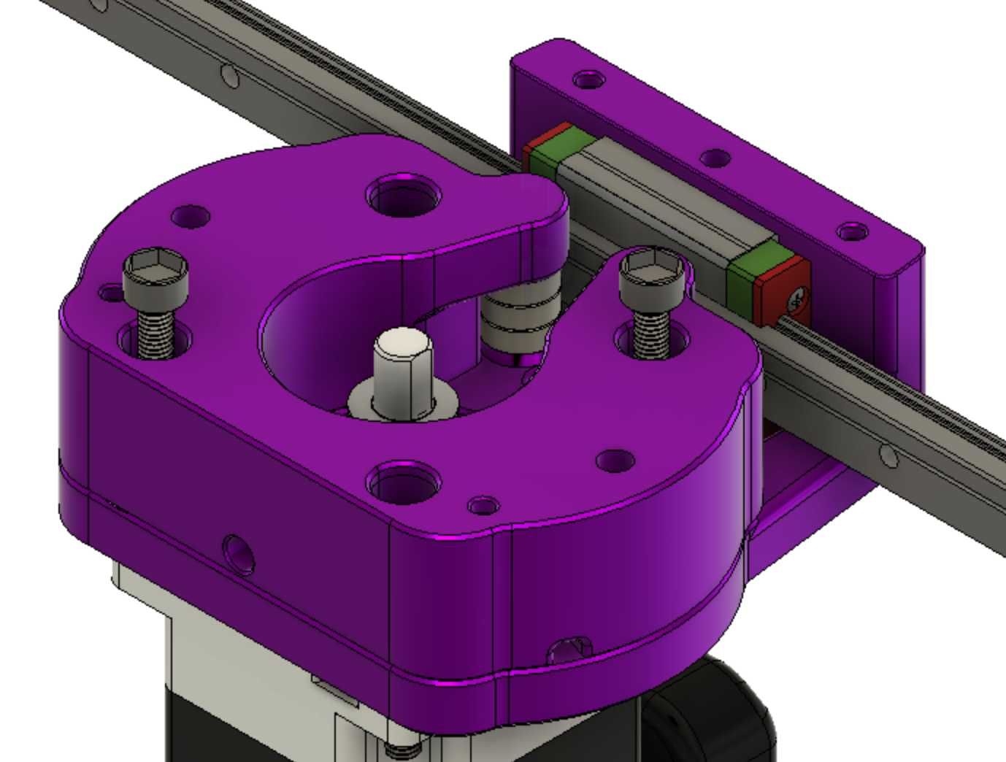
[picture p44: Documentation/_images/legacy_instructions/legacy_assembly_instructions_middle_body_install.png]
\

### Alternate Middle – Pivot

The new middle pivot design makes it easier to bolt your ossm directly onto extrusion. It can be mounted using 4x M5x35 screws and 4x M5 nuts as shown below.

Here all 4 bolts go through the motor, ossm base, and ossm middle.

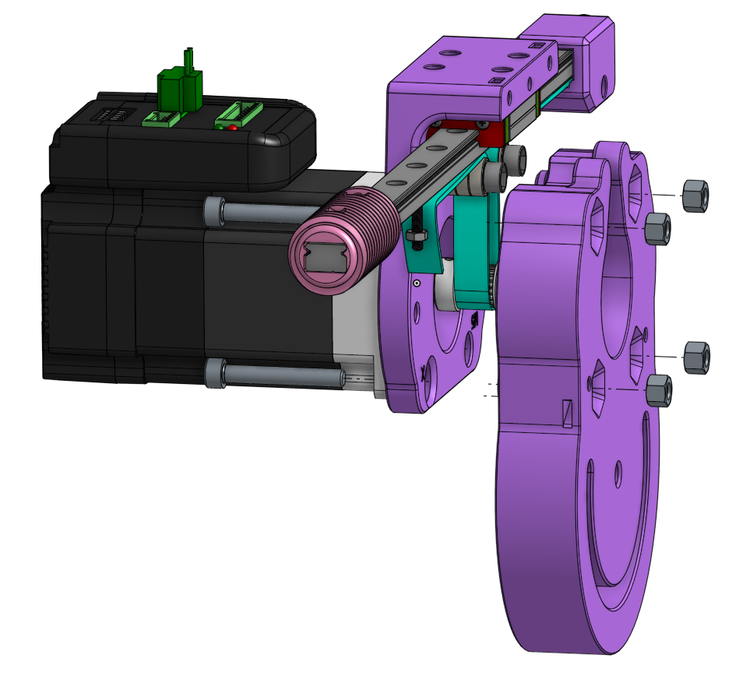
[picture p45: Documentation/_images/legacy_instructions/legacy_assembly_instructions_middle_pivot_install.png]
\

### Belt Placement

Now is time to place the belt in the iconic OSSM configuration. Using the clamp files provided to secure and tension the belt.\
Belt is shown in BLUE\
The teeth on the belt are not shown, but should face the pulley.

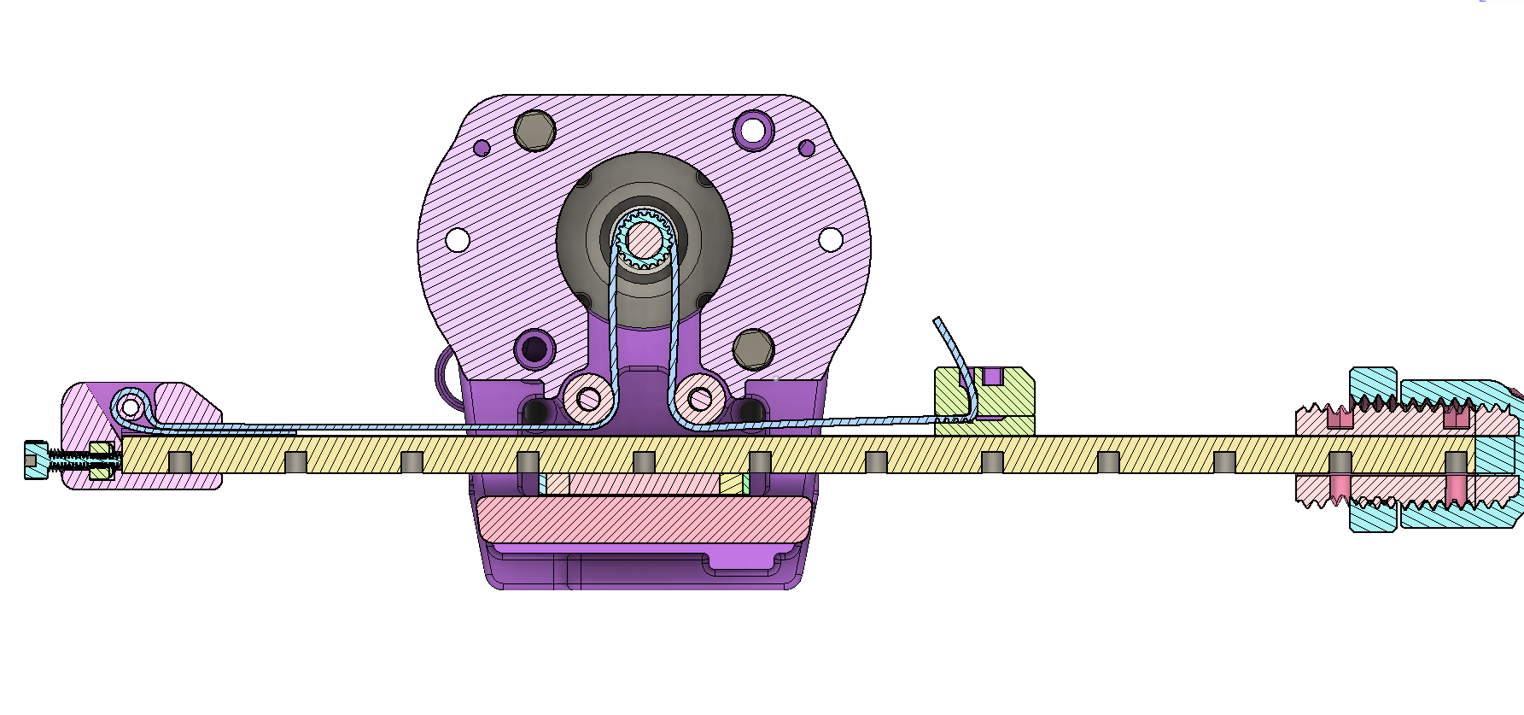
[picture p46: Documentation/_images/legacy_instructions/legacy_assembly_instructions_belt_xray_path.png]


X-Ray View of entire belt path

\

### Belt Tensioner

Start with getting the belt placed into the tensioner. Fold the belt in half with the teeth facing towards each other. Work each end in from the top following the green arrows below.\
Pull the belt until the lower piece has only a small section sticking out from the tensioner.

Then slip the assembly onto the end of the rail.

Drop an M5 nut into the slot and thread in an M5x16 screw into it. Tightening this screw will push on the rail and apply more tension – be gentle here! We just want to take up the slack, it is easy to apply way too much force if you tighten this too much. Too much force can damage your motor bearings!

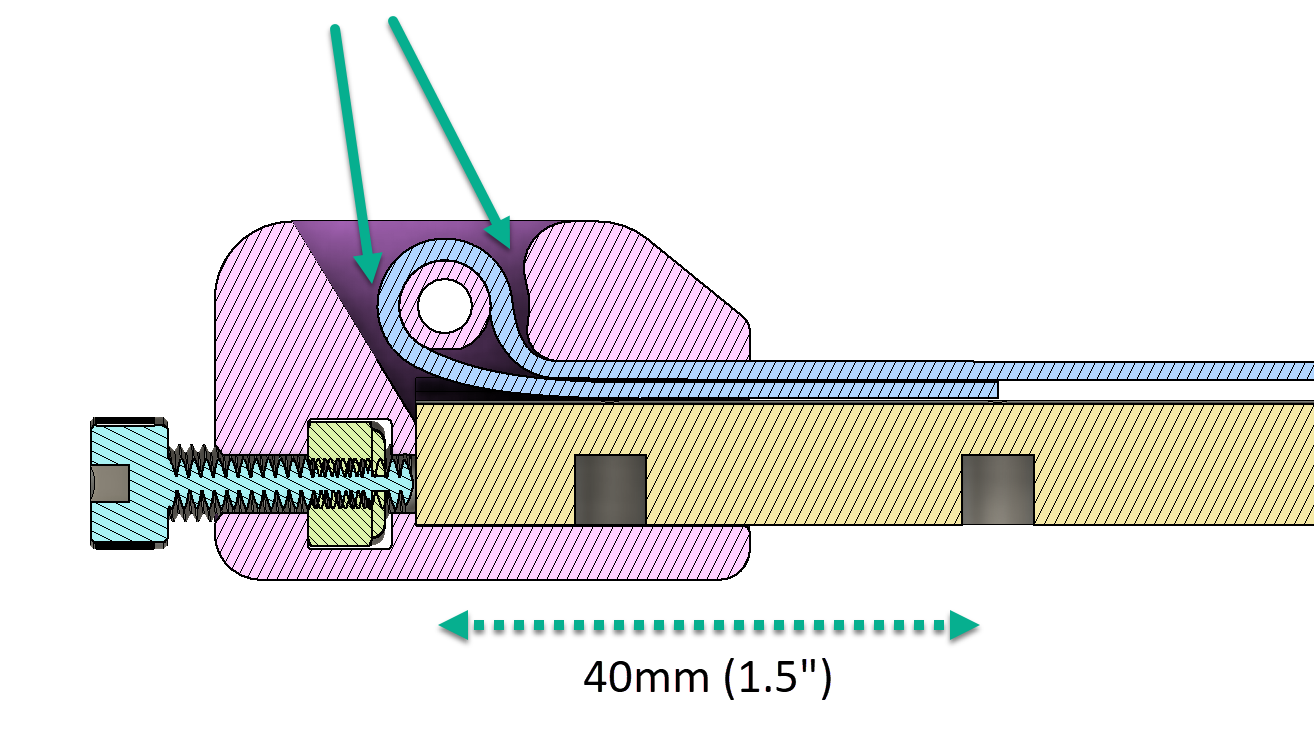
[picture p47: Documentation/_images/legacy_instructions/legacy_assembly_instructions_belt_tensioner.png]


### Wrap Belt Around Pulley

Wrapping the belt around the main drive pully and past the stacks of idler pulleys will get the belt in the correct location.

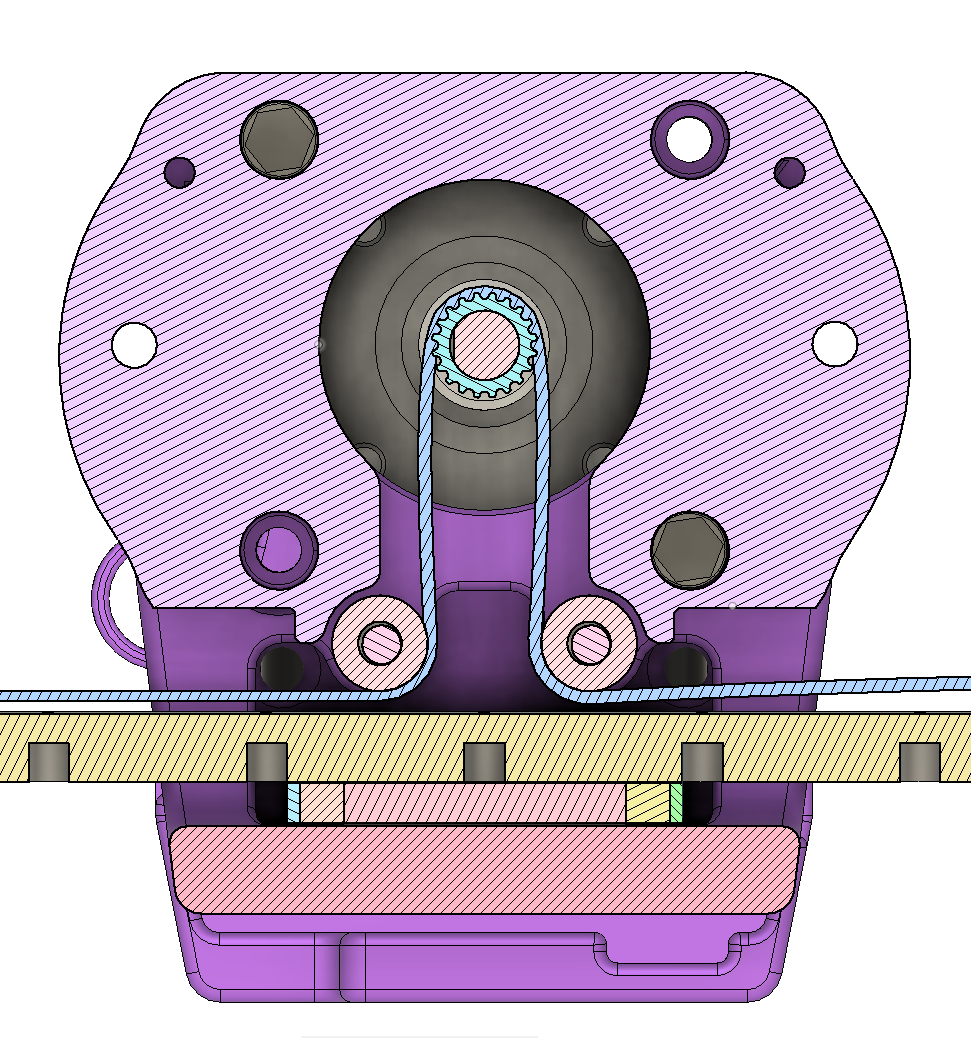
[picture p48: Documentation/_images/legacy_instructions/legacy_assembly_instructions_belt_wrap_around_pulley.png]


### Belt Clamp

* The belt routes through the slot in the top belt clamp. Insert the M3x20 screw from the bottom of the rail, through the clamp bottom (with teeth up engaging the belt), and engage the nut in the top clamp.
* Before you tighten the screw fully, pull the remaining belt slack so it is snug.
* Tighten the screw to secure the belt.
* Trim remaining belt (if you are sure you are happy with stroke length!)

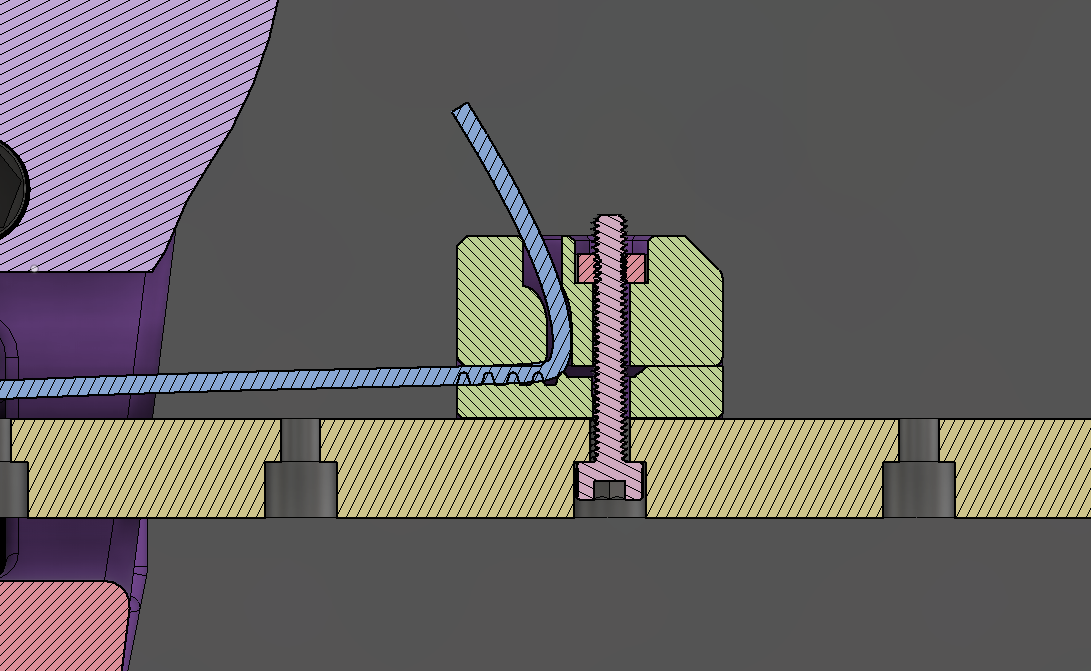
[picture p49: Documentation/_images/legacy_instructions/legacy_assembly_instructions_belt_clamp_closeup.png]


Congratulations!

(we hope) You should now have a mechanically assembled OSSM Reach out on the discord if you have any issues!

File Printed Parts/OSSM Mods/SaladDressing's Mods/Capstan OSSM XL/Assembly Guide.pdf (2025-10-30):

1. Bushing Pulley/Spindle/Drum/Capstan:
1. With the Bushing Pulley files printed, make sure the Bushing/Bearing Shell fits on top of the drum. Shouldn't be too loose or too tight. Top Part needs to fit on top as well with a somewhat secure fit. Also assure the pulley fits onto the motor shaft. Shouldn’t be too tight or loose. If things don't fit, adjust with the included .f3d file or pm me.
2. Spread some epoxy 2 part glue on the printed file.
3. Slide the Bushing/Bearing Shell on top. Put on the top part as well.
4. Put some weight on the Pulley and let it dry for 24h under pressure
5. Make sure the bushing holds well. It should be very rigid.
6. Wrap some grippy tape around the pulley. I used kinesio tape, which works quite well

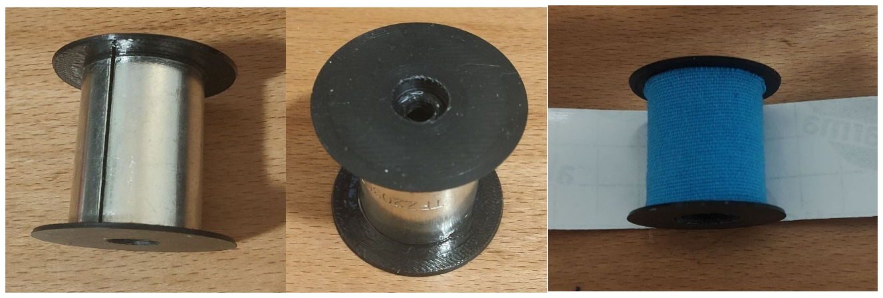
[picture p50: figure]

2. Clean the MGN12H Rail and Wagon (e.g. soaking in 99% isopropyl alcohol)
3. Screw the MGN12H Rail wagon to the Motor Head Back with 4 HexCap M3x12 screws
4. Mount the Motor Head Back to the Motor with Armpit’s 60AIM40F Ring behind (optional, if you want PitClamp Mounting) with 2 Hex Cap M5x45, 2 Countersunk M5x45 Screws and 4 M5 Nuts on the back. Make sure the Motor Terminal and the Notch in the Motor Ring are aligned to each other and the cable hole in the Motor Head Back right below the motor shaft.

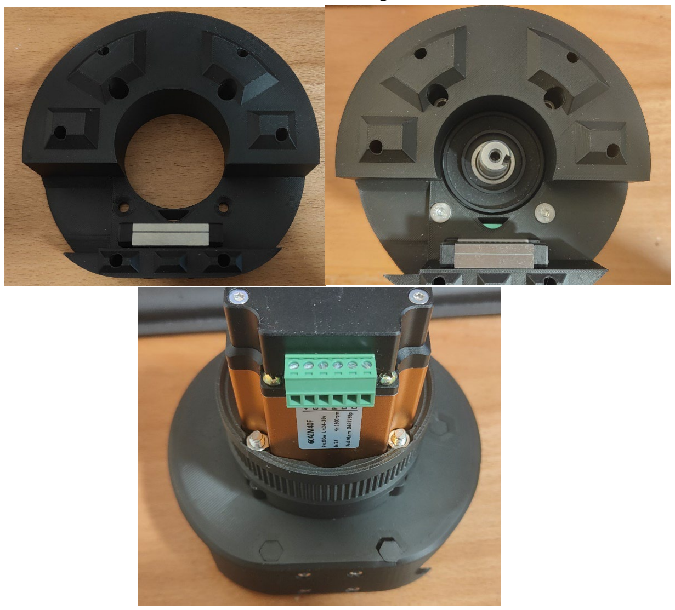
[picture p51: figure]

5. Insert 2 MR115 bearings into the 8mm end pulley, 3 MR115 bearings into the 12mm end pulley.
6. Secure the 8mm Pulley to the end effector and the 12mm end pulley to the rail end with a ISO 7380 M5x20 screw each.
7. Slide End Effector and Rail End onto the rail as pictured below. Secure the End Effector with 2x M3x16 Hex Cap Screws and the Rail End with 1x M3x12 Hex Cap Screw

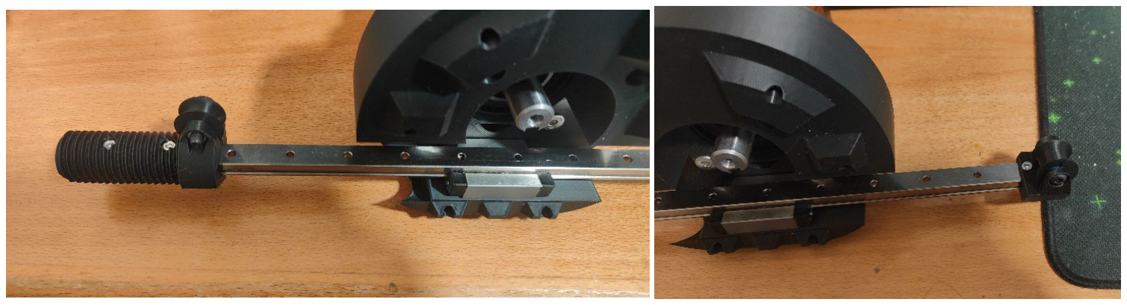
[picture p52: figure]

8. Channel the jst and 2 pin cable through the central hole below the motor shaft on the Motor Head Back
9. Slide the Pulley onto the motor head. Do not slide it on completely, just push it on enough for it to have a somewhat stable fit. This will make the wrapping of the rope easier.
10. Slide the motor head on the rail so it is roughly centered to the usable rail.
11. Take the rope and tie one end to a hole on the rail of your choosing. This makes the wrapping of the rope easier. Leave a generous length of rope on this end. Do not cut the rope.
12. Guide the rope around the end pulleys and the capstan like pictured below.

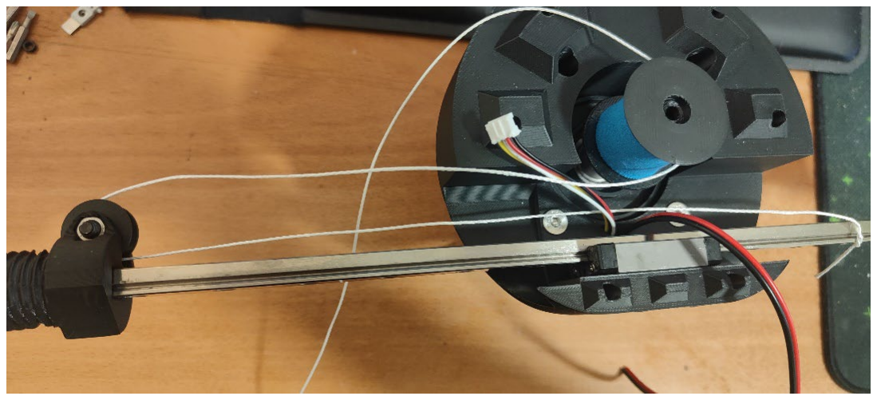
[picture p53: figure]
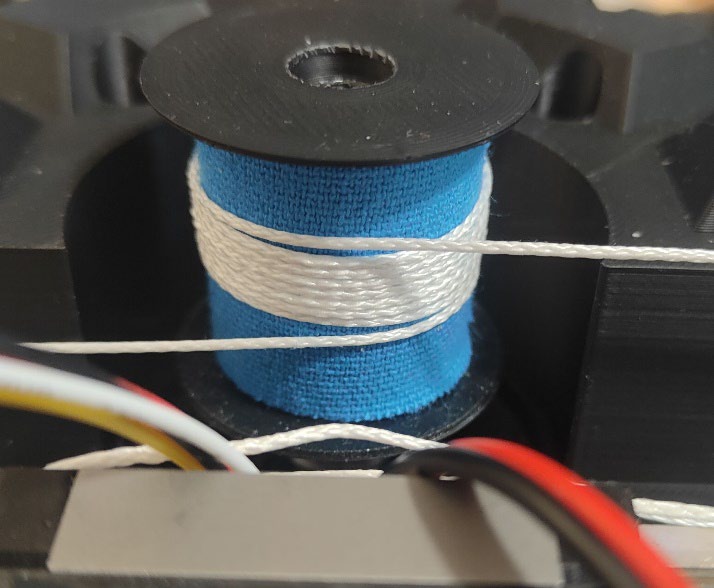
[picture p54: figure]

13. Wrap the rope rather tightly around the capstan pulley. Try to keep the wraps on the drum roughly centered. The amount of wraps I used was 8, which works well with the Kinesio tape I used. Your mileage may vary depending on which tape you used. This is something you may need to play around with. More wraps have only the disadvantage of taking up more space, which makes it not possible to accommodate higher rail lengths. 8 wraps works well with 450mm rail length. Not enough wraps will result in slipping of the rope. The more wraps, the harder it is for the rope to slip.

14. If you use the 3d printed Pulley with the integrated grooves (not the bushing pulley), same applies here, though you will need less wraps. 5 was enough if I remember correctly.
15. Guide the rope as pictured below


16. You can let go of the rope. This will relieve some tension from the wraps, but that is no problem, we can tension it as much as we like later.
17. Push the pulley onto the motor shaft completely. Screw it onto the shaft using a ISO 7380 M5x12 screw. You don’t need to screw it very tight.
18. Take the Motor Head Front part. Push in the standoffs in the fitting slots. Use violence if needed.
19. Push 4 M4 and 1 M5 Nuts into the lower part of the tensioner.
20. Insert the lower part of the tensioner into the Motor Head front part as pictured below. Insert the M5x80 screw from the appropriate hole on top and screw it into the lower tensioner part.


21. Push the Tensioner around a bit to make sure it moves around.
22. Put the Motor Head Front onto the Motor Head Back. For this, first guide the jst and 2 pin cables through the hole just below the tensioner. Then untie the rope end and guide both rope ends through the same hole.


23. Insert 4 ISO 7380 M4x12 screws into the tensioner top part.
24. Tension the rope ends and pull them over the teeth of the tensioner.
25. Place the tensioner top part onto the lower part and screw it tight. You can make it quite tight.


26. Make sure the rope goes over the little blocks on the underside of the Motor Head Front, as pictured below


27. Mount the Top with 2 M5x45 Hex Cap screws and 2 M5 Nuts on the back
28. Now turn the M5x80 screw to tension the rope. Tension it guitar string tight. Move around the rail a bit and see if anything is wrong. The motion should be very fluent. Make sure the rope wraps are roughly centered on the capstan pulley. If they are not, it may be that it gets hard to push the rail to the end because the rope wraps over itself (thus increasing diameter of the capstan pulley -> longer rope needed). If you have issues with this and can’t get it to work, feel free to write on discord.

29. Hold the rope ends tightly, screw of the tensioner top part, and reset the position of the tensioner back down again. Then screw in the tensioner top part again. This is done so you have some redundancy in retensioning.
30. The rope will stretch a tiny bit over the first few hours of use. Retension accordingly to keep it guitar string tight or even tighter. The tighter the rope is tensioned, the less shifting on the rope on the drum you will have (in extreme conditions). However, too tight of a tension may damage the tape on the capstan pulley over time. Before use, always make sure the rope is properly tensioned.
31. Cut the rope now but leave some redundancy in length.
32. Crimp the cable ends with terminal crimps.
33. Plug the JST cable into the header on the ossm control board and screw in the cable ends into the terminal block
34. Place the ossm control board onto the standoffs with the side with the esp chip facing down.
35. Cut the cables to length and screw the other side into the motors terminal.
36. Finally, screw down the front cover with 4x M5x45 countersunk screws and 4x M5 Nuts on the back.


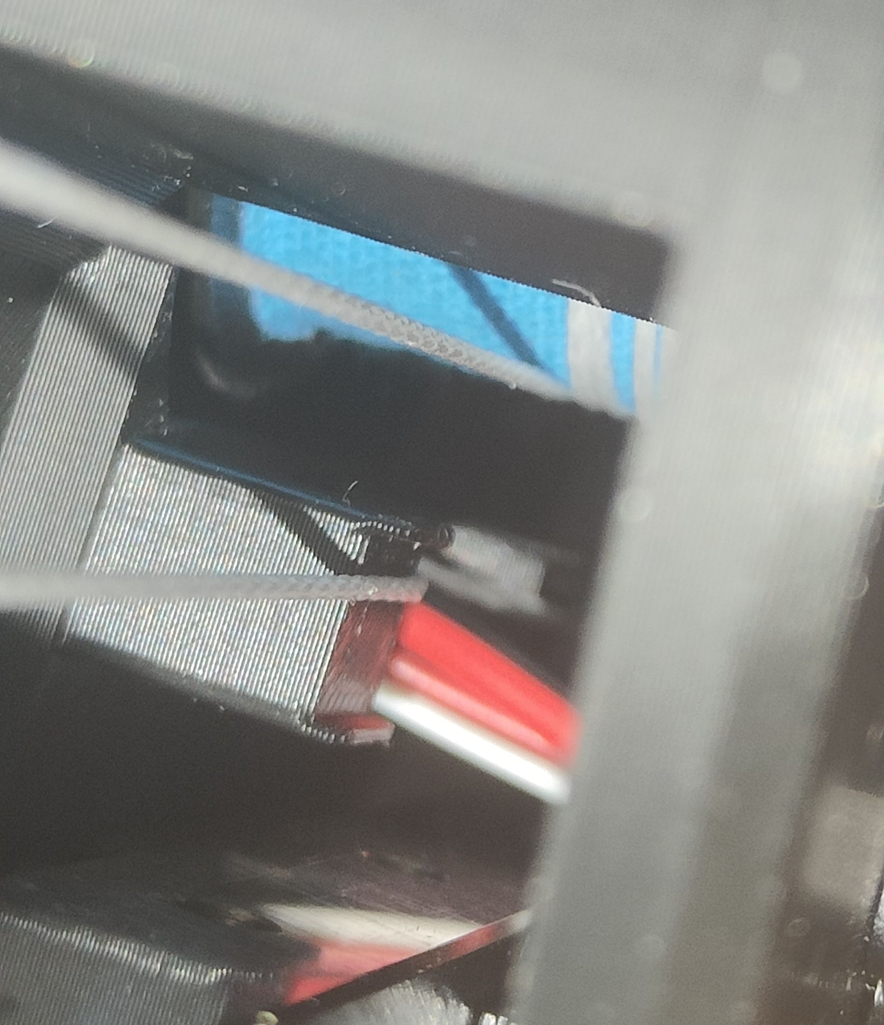
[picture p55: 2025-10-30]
Printed Parts/OSSM Mods/SaladDressing's Mods/Capstan OSSM XL/Pictures/Assembly/16.jpg

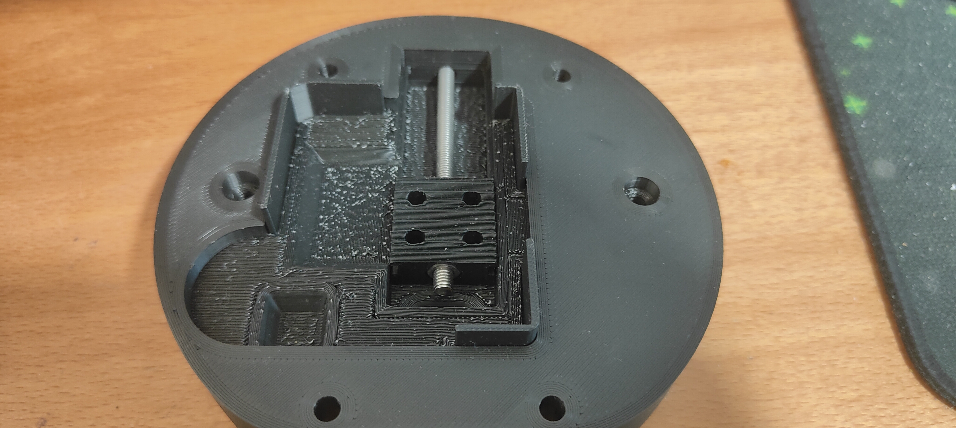
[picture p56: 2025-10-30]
Printed Parts/OSSM Mods/SaladDressing's Mods/Capstan OSSM XL/Pictures/Assembly/12.jpg

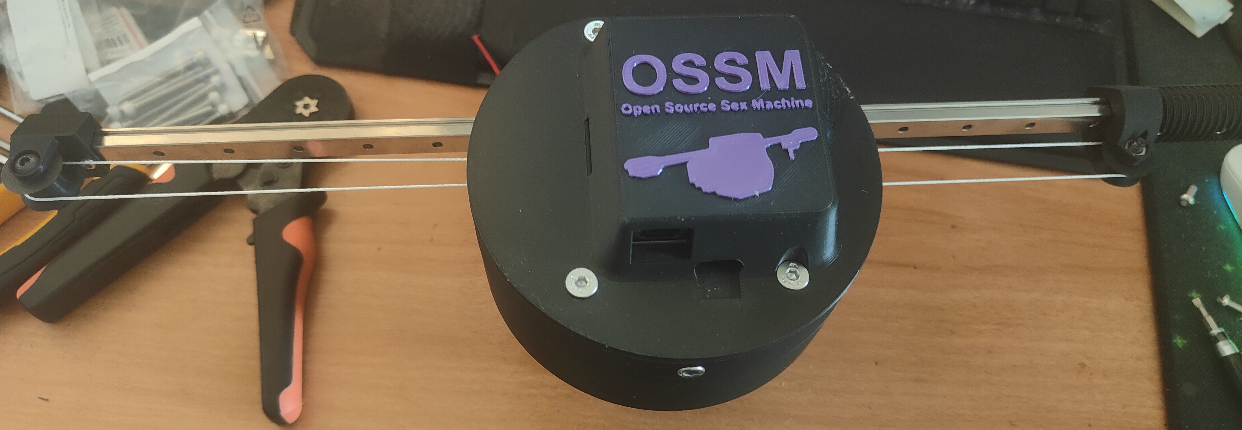
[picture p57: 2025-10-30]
Printed Parts/OSSM Mods/SaladDressing's Mods/Capstan OSSM XL/Pictures/Assembly/18.jpg

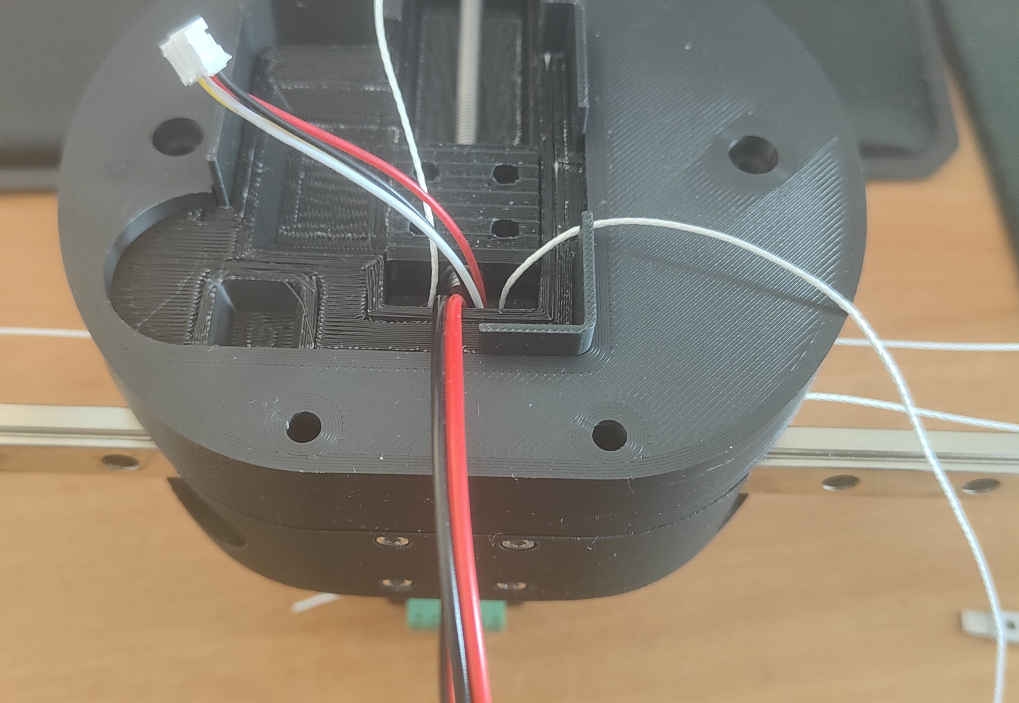
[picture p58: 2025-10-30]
Printed Parts/OSSM Mods/SaladDressing's Mods/Capstan OSSM XL/Pictures/Assembly/14.jpg

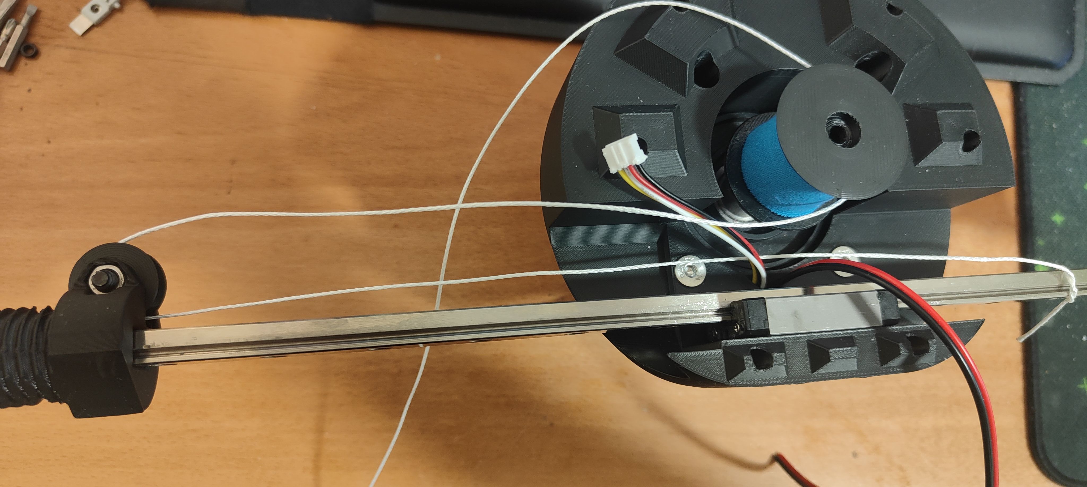
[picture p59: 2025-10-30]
Printed Parts/OSSM Mods/SaladDressing's Mods/Capstan OSSM XL/Pictures/Assembly/9.jpg

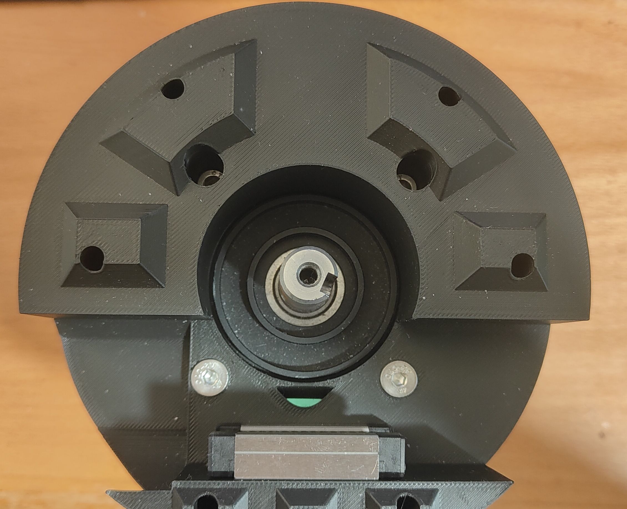
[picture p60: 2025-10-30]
Printed Parts/OSSM Mods/SaladDressing's Mods/Capstan OSSM XL/Pictures/Assembly/5.jpg

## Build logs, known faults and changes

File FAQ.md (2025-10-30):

# Frequently Asked Questions

### Q: What is OSSM?

A: An OSSM is compact sex machine that can be customised to suit you. Based around a NEMA23 pattern for electric motors it can be driven by stepper or best of all servo motors it uses a combination of 3D printed and off the shelf parts.

### Q: Why go to all this trouble? Why don't you just buy a ready made machine?

A: The OSSM is open you are not tied to a specific company and it does a lot more than equivalently priced machines. Best of all you can fully control the stroke speed and most importantly depth. You can make patterns or even your own control software. Maybe you want to add a stroker rather than a dildo, you can modifiy it to do that. Not enough power? You can use a bigger motor up to a certain point.

### Q: What parts do I need?

A: Head over to [the README](./#bill-of-materials) - the BOM is maintained there.

### Q: I've been reading about motors and now I'm really confused

A: While you can theoretically use any Nema23 mount motor. There are motors that work and some that work better. Stepper motors are cheaper and noiser so the community recommends closed loop servo motors. These are more efficient and more importantly easier to program.

### Q: What strength of motor do I need?

A: That depends on a couple of factors.

- Vaginal or Anal use
- Size of toys
- Anticipated Speed

We don't have a lot of recorded data [Please help us with this!] however the general suggestions are;

- **NEW 57AIM30 (Gold Motor)**: Roughly equivalent to **180W** below, see [Gold Motor Info](https://github.com/KinkyMakers/OSSM-hardware/blob/master/Documentation/Gold-Motor.md) and BOM.
- **100w** IHSV57 Servo: Vaginal usage with medium size toys and Anal usage with smaller toys (10 lbs force)
- **140W** IHSV57 Servo: Vaginal usage with larger toys, Anal use with medium size toys (15 lbs force)
- **180w** IHSV57 servo works with a wide range of toys for vaginal or anal play, and really packs a punch (20 lbs force). However if you like seriously heavy fantasy dildos you might want to consider building a Squooter [see the discord] that uses and even a larger motor mount; the NEMA34 which has even more powerful motors.

A build with a servo motor will have a flat torque curve across the speed range. That's to say - it will push just as hard at the slow speeds as well as the fast.
With a stepper, the most force will be at the slower speeds and the top speed of a stepper is much less than the servo we've chosen to work with.

### Q: Hold on, why does anal play need more powerful motors?

A: Butts have big powerful muscles! It's common for people to bear down, or clench when things are feeling really good. Also it can be pretty fun shoving big objects in there! It can take a big motor to handle a big toy in a poweful butt.

### Q: What sized 3D printer do I need?

A: The minimum bed size is 105mm x 105mm for the largest single piece. Approximately 125mm of height is required for the shorter vac-u-lock compatible adapter, the plate is significantly shorter.

### Q: What print material is best?

A: Structural parts should be printed in a strong material such as simple PLA, PETG, ABS, ASA, or PCTG. Non-structural parts may be printed in whatever material you like. Note that additives such as those used to make matte materials may weaken the material, so be sure to check the material properties before using a filament with additives. If you print in some new and unusual material, please share that in the Discord!

### Q: What is the infill percentage?

A: 30% has been found to work just fine with PLA for non flexible parts

### Q: How thick are the walls and top?

A: Recommend at least 3mm for non flexible parts.

### Q: What are these flexible parts and how should I print them?

A: There are mounting solutions that use clamps for the OSSM these need some flexiblity. For these parts thinner walls 2mm, lower infill percentages and a gyroid pattern.

### Q: How do I mount toys onto the OSSM?

A: Aside from the motor this is second decision. There is a vacc-u-lock compatible mount the double double and a plate mount for suction cup toys that has some points to tie a dildo down The OSSM Platten

### Q: What to I mount the machine on?

A: Well there are a few designs available. THere are standard pipe mounts for US/Canadian along with 80/20 rails that can be used like a construction set. There are even manfrotto boom compatible adaptors. It is really limited by you imagination.

### Q: How do I control my OSSM

A: It depends on how you are going to use it. Basic OSSM control is via the wired remote and a more advanced remote is available from community members (M5 Remote). If you want something specific you can create your own that is the great thing about open source hardware.

### Q: I heard somewhere you can "control via a web page?" Can I get people to control my OSSM over the internet?

A: As of August 2023 you cannot control an OSSM over the internet. In the past R&D offered a web page that allowed very basic control with speed and depth settings over wifi.

### Q: X-Toy and funscript support. Where is it?

A: As of August 2023 there is a highly experimental X-toy firmware forked from an earlier version that requires endstops. This code has significant issue and is not considered to be safe for use on humans. There are frequent pauses, it loses track of where it is and has a tendency to randomly extend to maximum depth. Development of an X-Toys firmware is happening but it is complicated.

### Q: Why is X-Toys/Funscripts/ButtplugIO so difficult?

A: Things are a lot more complicated once you dig down into them.

- The motion core does not yet support position streaming. This is in development and requires a complete redesign of the safety architecture as you don't want to accidentally stab yourself.
- From the experimental software we learnt that the latency margin is really thin, Bluetooth especially struggles here. This will be a challenge to overcome.
- The data models of both xtoys and Buttplug.io do not support complex data models as it would be required for OSSM out of the box. As scaling to the full length of OSSM is just not an option. There might be a workaround by emulating an other toy. But you won't be able to control all aspects of OSSM through this.

### Q: There is an OSSM reference board do I have to buy it to make an OSSM?

A: No you don't but it does make building an OSSM a lot easier and stops you having to solder anything.

### Q: Powersupplies what size do I need?

A: That is linked to the size of motor. The higher the wattage of motor the larger the powersupply you need. For safety use a desktop power supply that is ideally double insulated. Power supplies from Mouser/Digikey/Conrad/RS etc are all typically more expensive than "no brand supplies" you get from AliExpress/eBay/Amazon. Experience has been mixed with unbranded supplies with occasional quality and longer term stability issues.

- 100w JMC we currently suggest a 4A 24V Supply
- 140w /180w JMC we currently suggest a 6A 24V

### Q: How long should the H-rail be?

A: It is really up to you but a 350mm rail will give approximately 195mm of depth.

### Q: What is the size of the 24mm Thread for the End Effector?

A: It is a M24x3 (this is the size on the machine, do a test print for your new End Effector, you may have to upsize by 3-5%)

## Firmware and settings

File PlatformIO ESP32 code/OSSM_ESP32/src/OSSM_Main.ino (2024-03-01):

#include <Arduino.h>          // Basic Needs
#include <ArduinoJson.h>      // Needed for the Bubble APP
#include <ESP_FlexyStepper.h> // Current Motion Control
#include <Encoder.h>          // Used for the Remote Encoder Input
#include <HTTPClient.h>       // Needed for the Bubble APP
#include <WiFiManager.h>      // Used to provide easy network connection  https://github.com/tzapu/WiFiManager
#include <Wire.h>             // Used for i2c connections (Remote OLED Screen)

#include "OSSM_Config.h" // START HERE FOR Configuration
#include "OSSM_PinDef.h" // This is where you set pins specific for your board
#include "OssmUi.h"      // Separate file that helps contain the OLED screen functions
#include "Stroke_Engine_Helper.h"
#include "Utilities.h" // Utility helper functions - wifi update and homing

// Homing
volatile bool g_has_not_homed = true;
bool REMOTE_ATTACHED = false;

// OSSM name setup
const char *ossmId = "OSSM1";
volatile int encoderButtonPresses = 0; // increment for each click
volatile long lastEncoderButtonPressMillis = 0;

IRAM_ATTR void encoderPushButton()
{
    // TODO: Toggle position mode
    // g_encoder.write(0);       // Reset on Button Push
    // ossm.g_ui.NextFrame();         // Next Frame on Button Push

    // debounce check
    long currentTime = millis();
    if ((currentTime - lastEncoderButtonPressMillis) > 200)
    {
        // run interrupt if not run in last 50ms
        encoderButtonPresses++;
        lastEncoderButtonPressMillis = currentTime;
    }
}

// Current command state
// volatile float strokePercentage = 0;
// volatile float ossm.speedPercentage = 0;
// volatile float deceleration = 0;

// Create tasks for checking pot input or web server control, and task to handle
// planning the motion profile (this task is high level only and does not pulse
// the stepper!)
TaskHandle_t wifiTask = nullptr;
TaskHandle_t getInputTask = nullptr;
TaskHandle_t motionTask = nullptr;
TaskHandle_t estopTask = nullptr;
TaskHandle_t oledTask = nullptr;

// Declarations
// TODO: Document functions
// void setLedRainbow(CRGB leds[]);
void getUserInputTask(void *pvParameters);
void motionCommandTask(void *pvParameters);
void wifiConnectionTask(void *pvParameters);

// create the OSSM hardware object
OSSM ossm;

///////////////////////////////////////////
////
////  VOID SETUP -- Here's where it's hiding
////
///////////////////////////////////////////

void setup()
{
    ossm.startLeds();
    Serial.begin(115200);
    LogDebug("\n Starting");
    pinMode(ENCODER_SWITCH, INPUT_PULLDOWN); // Rotary Encoder Pushbutton
    attachInterrupt(digitalPinToInterrupt(ENCODER_SWITCH), encoderPushButton, RISING);

    ossm.setup();

    // start the WiFi connection task so we can be doing something while homing!
    xTaskCreatePinnedToCore(wifiConnectionTask,   /* Task function. */
                            "wifiConnectionTask", /* name of task. */
                            10000,                /* Stack size of task */
                            NULL,                 /* parameter of the task */
                            1,                    /* priority of the task */
                            &wifiTask,            /* Task handle to keep track of created task */
                            0);                   /* pin task to core 0 */
    delay(100);

    ossm.findHome();

    ossm.setRunMode();

    // Kick off the http and motion tasks - they begin executing as soon as they
    // are created here! Do not change the priority of the task, or do so with
    // caution. RTOS runs first in first out, so if there are no delays in your
    // tasks they will prevent all other code from running on that core!
    xTaskCreatePinnedToCore(getUserInputTask,   /* Task function. */
                            "getUserInputTask", /* name of task. */
                            10000,              /* Stack size of task */
                            NULL,               /* parameter of the task */
                            1,                  /* priority of the task */
                            &getInputTask,      /* Task handle to keep track of created task */
                            0);                 /* pin task to core 0 */
    delay(100);
    xTaskCreatePinnedToCore(motionCommandTask,   /* Task function. */
                            "motionCommandTask", /* name of task. */
                            20000,               /* Stack size of task */
                            NULL,                /* parameter of the task */
                            1,                   /* priority of the task */
                            &motionTask,         /* Task handle to keep track of created task */
                            0);                  /* pin task to core 0 */

    delay(100);
    ossm.g_ui.UpdateMessage("OSSM Ready to Play");
} // Void Setup()

///////////////////////////////////////////
////
////
////   VOID LOOP - Hides here
////
////
///////////////////////////////////////////

void loop()
{
    switch (ossm.rightKnobMode)
    {
        case MODE_STROKE:
            ossm.g_ui.UpdateState("STROKE", static_cast<int>(ossm.speedPercentage),
                                  static_cast<int>(ossm.strokePercentage + 0.5f));
            break;
        case MODE_DEPTH:
            ossm.g_ui.UpdateState("DEPTH", static_cast<int>(ossm.speedPercentage),
                                  static_cast<int>(ossm.depthPercentage + 0.5f));
            break;
        case MODE_SENSATION:
            ossm.g_ui.UpdateState("SENSTN", static_cast<int>(ossm.speedPercentage),
                                  static_cast<int>(ossm.sensationPercentage + 0.5f));
            break;
        case MODE_PATTERN:
            ossm.g_ui.UpdateState("PATTRN", static_cast<int>(ossm.speedPercentage),
                                  ossm.strokePattern * 100 / (ossm.strokePatternCount - 1));
            break;
    }
    ossm.g_ui.UpdateScreen();

    // debug
    static bool is_connected = false;
    if (!is_connected && ossm.g_ui.DisplayIsConnected())
    {
        LogDebug("Display Connected");
        is_connected = true;
    }
    else if (is_connected && !ossm.g_ui.DisplayIsConnected())
    {
        LogDebug("Display Disconnected");
        is_connected = false;
    }
}

///////////////////////////////////////////
////
////
////  freeRTOS multitasking
////
////
///////////////////////////////////////////

void wifiConnectionTask(void *pvParameters)
{
    ossm.wifiConnectOrHotspotNonBlocking();
}

// Task to read settings from server - only need to check this when in WiFi
// control mode
void getUserInputTask(void *pvParameters)
{
    float targetSpeedMmPerSecond = 0;
    float targetAccelerationMm = 0;
    float previousSpeedPercentage = 0;
    for (;;) // tasks should loop forever and not return - or will throw error in
             // OS
    {
        // LogDebug("Speed: " + String(ossm.speedPercentage) + "\% Stroke: " + String(ossm.strokePercentage) +
        //          "\% Distance to target: " + String(ossm.stepper.getDistanceToTargetSigned()) + " steps?");

        ossm.updateAnalogInputs();
        //ossm.printSensorReadings();
        ossm.handleStopCondition();

        if (digitalRead(WIFI_CONTROL_TOGGLE_PIN) == HIGH) // TODO: check if wifi available and handle gracefully
        {
            ossm.enableWifiControl();
        }
        else
        {
            if (ossm.wifiControlActive == true)
            {
                // this is a transition to local control, we should tell the server it cannot control

                ossm.setInternetControl(false);
            }
        }

        // We should scale these values with initialized settings not hard coded
        // values!
        if (ossm.speedPercentage > ossm.commandDeadzonePercentage)
        {
            targetSpeedMmPerSecond = ossm.maxSpeedMmPerSecond * ossm.speedPercentage / 100.0;
            if ((ossm.speedPercentage - previousSpeedPercentage) > 30)
            {
                targetSpeedMmPerSecond =
                    0.5 * (ossm.speedPercentage + previousSpeedPercentage) * ossm.maxSpeedMmPerSecond / 100.0;
            }
            targetAccelerationMm =
                ossm.maxSpeedMmPerSecond * ossm.speedPercentage * ossm.speedPercentage / ossm.accelerationScaling;

            ossm.stepper.setAccelerationInMillimetersPerSecondPerSecond(targetAccelerationMm);
            if (targetSpeedMmPerSecond > ossm.stepper.getCurrentVelocityInMillimetersPerSecond())
            { // we are speeding up, we need to increase deccel rate!
                ossm.stepper.setDecelerationInMillimetersPerSecondPerSecond(targetAccelerationMm);
            }

            ossm.stepper.setSpeedInMillimetersPerSecond(targetSpeedMmPerSecond);

            // If target speed is lower than current, we do not update deccel as setting a low decel when going from
            // high to low speed causes the motor to travel a long distance before slowing.
        }
        previousSpeedPercentage = ossm.speedPercentage;
        vTaskDelay(80); // let other code run!
    }
}

void motionCommandTask(void *pvParameters)
{
    for (;;) // tasks should loop forever and not return - or will throw error in
             // OS
    {
        switch (ossm.activeRunMode)
        {
            case ossm.simpleMode:
                ossm.runPenetrate();
                break;

            case ossm.strokeEngineMode:
                ossm.runStrokeEngine();
                break;
        }
    }
}

// float getAnalogVoltage(int pinNumber, int samples){

// }

// void setLedRainbow(CRGB leds[])
// {
//     // int power = 250;

//     for (int hueShift = 0; hueShift < 350; hueShift++)
//     {
//         int gHue = hueShift % 255;
//         fill_rainbow(leds, NUM_LEDS, gHue, 25);
//         FastLED.show();
//         delay(4);
//     }
// }

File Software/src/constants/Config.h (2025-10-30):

#ifndef OSSM_SOFTWARE_CONFIG_H
#define OSSM_SOFTWARE_CONFIG_H

/**
    Default Config for OSSM - Reference board users should tweak UserConfig to
   match their personal build.

    //TODO: restore user overrides with a clever null coalescing operator
*/
namespace Config {

    /**
            Motion System Config
    */
    namespace Driver {

        // Top linear speed of the device.
        constexpr float maxSpeedMmPerSecond = 900.0f;

        // Top acceleration of the device.
        constexpr float maxAcceleration = 10000.0f;

        // This should match the step/rev of your stepper or servo.
        // N.b. the iHSV57 has a table on the side for setting the DIP switches
        // to your preference.
        constexpr float motorStepPerRevolution = 800.0f;

        // Number of teeth the pulley that is attached to the servo/stepper
        // shaft has.
        constexpr float pulleyToothCount = 20.0f;

        // Set to your belt pitch (Distance between two teeth on the belt) (E.g.
        // GT2 belt has 2mm tooth pitch)
        constexpr float beltPitchMm = 2.0f;

        // This is the measured current that use to infer when the device has
        // reached the end of its stroke. during "Homing".
        constexpr float sensorlessCurrentLimit = 1.5f;

        constexpr float stepsPerMM =
            motorStepPerRevolution / (pulleyToothCount * beltPitchMm);

        namespace Operator {
            // Define user-defined literal for unsigned integer values
            constexpr long long operator"" _mm(unsigned long long x) {
                return x * stepsPerMM;
            }

            // Define user-defined literal for floating-point values
            constexpr long double operator"" _mm(long double x) {
                return x * stepsPerMM;
            }
        }

        using namespace Operator;

        // This is in millimeters, and is what's used to define how much of
        // your rail is usable.
        // The absolute max your OSSM would have is the distance between the
        // belt attachments subtract the linear block holder length (75mm on
        // OSSM) Recommended to also subtract e.g. 20mm to keep the backstop
        // well away from the device.
        constexpr float maxStrokeSteps = 500.0_mm;

        // If the stroke length is less than this value, then the stroke is
        // likely the result of a poor homing.
        constexpr float minStrokeLengthMm = 50.0_mm;
    }

    /**
        Web Config
*/
    namespace Web {
        // This should be unique to your device. You will use this on the
        // web portal to interact with your OSSM.
        // there is NO security other than knowing this name, make this unique
        // to avoid collisions with other users
        constexpr char *ossmId = nullptr;
    }

    /**
        Font Config. These must be the "f" variants of the font to support other
       languages.
*/
    namespace Font {
        static auto bold = u8g2_font_helvB08_tf;
        static auto base = u8g2_font_helvR08_tf;
        static auto small = u8g2_font_6x10_tf;
    }

    /**
        Advanced Config
*/
    namespace Advanced {

        // After homingStart this is the physical buffer distance from the
        // effective zero to the home switch This is to stop the home switch
        // being smacked constantly
        constexpr float strokeZeroOffsetMm = 6.0f;
        // The minimum value of the pot in percent
        // prevents noisy pots registering commands when turned down to zero by
        // user
        constexpr float commandDeadZonePercentage = 1.0f;
        // affects acceleration in stepper trajectory (Aggressiveness of motion)

        constexpr float accelerationScaling = 100.0f;

    }

}

// Alias for "_mm" operator
using namespace Config::Driver::Operator;

#endif  // OSSM_SOFTWARE_CONFIG_H

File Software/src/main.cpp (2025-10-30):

#include "Arduino.h"
#include "OneButton.h"
#include "components/HeaderBar.h"
#include "ossm/Events.h"
#include "ossm/OSSM.h"
#include "ossm/OSSMI.h"
#include "services/board.h"
#include "services/communication/nimble.h"
#include "services/display.h"
#include "services/encoder.h"
#include "services/stepper.h"
#include "services/led.h"
#include "services/wm.h"

/*
 *  ██████╗ ███████╗███████╗███╗   ███╗
 * ██╔═══██╗██╔════╝██╔════╝████╗ ████║
 * ██║   ██║███████╗███████╗██╔████╔██║
 * ██║   ██║╚════██║╚════██║██║╚██╔╝██║
 * ╚██████╔╝███████║███████║██║ ╚═╝ ██║
 *  ╚═════╝ ╚══════╝╚══════╝╚═╝     ╚═╝
 *
 * Welcome to the open source sex machine!
 * This is a product of Kinky Makers and is licensed under the MIT license.
 *
 * Research and Desire is a financial sponsor of this project.
 *
 * But our biggest sponsor is you! If you want to support this project, please
 * contribute, fork, branch and share!
 */

OneButton button(Pins::Remote::encoderSwitch, false);

void setup() {
    /** Board setup */
    initBoard();

    ESP_LOGD("MAIN", "Starting OSSM");

    initWM();

    // Display
    initDisplay();

    // Initialize header bar task
    initHeaderBar();

    ossm = new OSSM(display, encoder, stepper);
    ossmInterface = ossm;

    // Initialize LED for BLE and machine status indication
    ESP_LOGI("MAIN", "LED initialized for BLE and machine status indication");
    updateLEDForMachineStatus();  // Set initial LED state

    // // link functions to be called on events.
    button.attachClick([]() { ossm->sm->process_event(ButtonPress{}); });
    button.attachDoubleClick([]() { ossm->sm->process_event(DoublePress{}); });
    button.attachLongPressStart([]() { ossm->sm->process_event(LongPress{}); });

    xTaskCreatePinnedToCore(
        [](void *pvParameters) {
            while (true) {
                button.tick();
                vTaskDelay(25 / portTICK_PERIOD_MS);
            }
        },
        "buttonTask", 4 * configMINIMAL_STACK_SIZE, nullptr,
        configMAX_PRIORITIES - 1, nullptr, 0);

    // Initialize NimBLE only when in menu.idle state
    xTaskCreatePinnedToCore(
        [](void *pvParameters) {
            bool initialized = false;
            while (true) {
                if ((ossm->sm->is("menu.idle"_s) ||
                     ossm->sm->is("error.idle"_s)) &&
                    !initialized) {
                    ESP_LOGD("MAIN", "Initializing NimBLE");
                    initNimble();
                    initialized = true;
                    vTaskDelete(nullptr);
                }
                vTaskDelay(pdMS_TO_TICKS(100));
            }
        },
        "initNimbleTask", 6 * configMINIMAL_STACK_SIZE, nullptr,
        configMAX_PRIORITIES - 1, nullptr, 0);
};

void loop() { vTaskDelete(nullptr); };

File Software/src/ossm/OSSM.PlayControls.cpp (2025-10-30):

#include "OSSM.h"

#include "constants/UserConfig.h"
#include "extensions/u8g2Extensions.h"
#include "services/tasks.h"
#include "utils/analog.h"
#include "utils/format.h"

void OSSM::drawPlayControlsTask(void *pvParameters) {
    // parse ossm from the parameters
    OSSM *ossm = (OSSM *)pvParameters;
    ossm->encoder.setAcceleration(10);
    ossm->encoder.setBoundaries(0, 100, false);
    // Clean up!
    switch (ossm->playControl) {
        case PlayControls::STROKE:
            ossm->encoder.setEncoderValue(OSSM::setting.stroke);
            break;
        case PlayControls::SENSATION:
            ossm->encoder.setEncoderValue(OSSM::setting.sensation);
            break;
        case PlayControls::DEPTH:
            ossm->encoder.setEncoderValue(OSSM::setting.depth);
            break;
    }

    auto menuString = menuStrings[ossm->menuOption];

    SettingPercents next = {0, 0, 0, 0};
    unsigned long displayLastUpdated = 0;

    /**
     * /////////////////////////////////////////////
     * /////////// Play Controls Display ///////////
     * /////////////////////////////////////////////
     *
     * This is a safety feature to prevent the user from accidentally beginning
     * a session at max speed. After the user decreases the speed to 0.5% or
     * less, the state machine will be allowed to continue.
     */
    auto isInCorrectState = [](OSSM *ossm) {
        // Add any states that you want to support here.
        return ossm->sm->is("simplePenetration"_s) ||
               ossm->sm->is("simplePenetration.idle"_s) ||
               ossm->sm->is("strokeEngine"_s) ||
               ossm->sm->is("strokeEngine.idle"_s) ||
               ossm->sm->is("streaming"_s);
    };

    // Line heights
    short lh3 = 56;
    short lh4 = 64;
    static float encoder = 0;

    bool isStrokeEngine =
        ossm->sm->is("strokeEngine"_s) || ossm->sm->is("strokeEngine.idle"_s);

    bool shouldUpdateDisplay = false;

    // This small break gives the encoder a minute to settle.
    vTaskDelay(100);

    String headerText = "";

    while (isInCorrectState(ossm)) {
        // Always assume the display should not update.
        shouldUpdateDisplay = false;

#ifdef AJ_DEVELOPMENT_HARDWARE
        next.speedKnob = 0;
#else
        next.speedKnob =
            getAnalogAveragePercent(SampleOnPin{Pins::Remote::speedPotPin, 50});
#endif
        OSSM::setting.speedKnob = next.speedKnob;
        encoder = ossm->encoder.readEncoder();

        if (USE_SPEED_KNOB_AS_LIMIT || !OSSM::setting.speedBLE.has_value()) {
            next.speed =
                next.speedKnob * (OSSM::setting.speedBLE.value_or(100)) / 100;
        } else {
            next.speedKnob = OSSM::setting.speedBLE.value_or(100);
            next.speed = OSSM::setting.speedBLE.value_or(100);
        }

        if (next.speed != OSSM::setting.speed) {
            shouldUpdateDisplay = true;
            OSSM::setting.speed = next.speed;
        }

        switch (ossm->playControl) {
            case PlayControls::STROKE:
                next.stroke = encoder;
                shouldUpdateDisplay = shouldUpdateDisplay ||
                                      next.stroke - OSSM::setting.stroke >= 1;
                OSSM::setting.stroke = next.stroke;
                break;
            case PlayControls::SENSATION:
                next.sensation = encoder;
                shouldUpdateDisplay =
                    shouldUpdateDisplay ||
                    next.sensation - OSSM::setting.sensation >= 1;
                OSSM::setting.sensation = next.sensation;
                break;
            case PlayControls::DEPTH:
                next.depth = encoder;
                shouldUpdateDisplay = shouldUpdateDisplay ||
                                      next.depth - OSSM::setting.depth >= 1;
                OSSM::setting.depth = next.depth;
                break;
        }

        shouldUpdateDisplay =
            shouldUpdateDisplay || millis() - displayLastUpdated > 1000;

        if (!shouldUpdateDisplay) {
            vTaskDelay(100);
            continue;
        }

        displayLastUpdated = millis();

        String strokeString = UserConfig::language.Stroke;
        auto stringWidth = ossm->display.getUTF8Width(strokeString.c_str());

        if (xSemaphoreTake(displayMutex, 100) == pdTRUE) {
            // Check and update the header text... don't worry if this is the
            // same as last time, nothing happens.
            if (isStrokeEngine) {
                headerText = UserConfig::language
                                 .StrokeEngineNames[(int)OSSM::setting.pattern];
            } else {
                headerText = UserConfig::language.SimplePenetration;
            }
            setHeader(headerText);

            // Now draw the page...
            clearPage(true);
            ossm->display.setFont(Config::Font::base);

            drawShape::settingBar(UserConfig::language.Speed, next.speedKnob);

            if (isStrokeEngine) {
                switch (ossm->playControl) {
                    case PlayControls::STROKE:
                        drawShape::settingBarSmall(OSSM::setting.sensation,
                                                   125);
                        drawShape::settingBarSmall(OSSM::setting.depth, 120);
                        drawShape::settingBar(strokeString,
                                              OSSM::setting.stroke, 118, 0,
                                              RIGHT_ALIGNED);
                        break;
                    case PlayControls::SENSATION:
                        drawShape::settingBar(F("Sensation"),
                                              OSSM::setting.sensation, 128, 0,
                                              RIGHT_ALIGNED, 10);
                        drawShape::settingBarSmall(OSSM::setting.depth, 113);
                        drawShape::settingBarSmall(OSSM::setting.stroke, 108);

                        break;
                    case PlayControls::DEPTH:
                        drawShape::settingBarSmall(OSSM::setting.sensation,
                                                   125);
                        drawShape::settingBar(F("Depth"), OSSM::setting.depth,
                                              123, 0, RIGHT_ALIGNED, 5);
                        drawShape::settingBarSmall(OSSM::setting.stroke, 108);

                        break;
                }
            } else {
                drawShape::settingBar(strokeString, ossm->encoder.readEncoder(),
                                      118, 0, RIGHT_ALIGNED);
            }
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

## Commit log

2022-07-23 serial output fixes and pak current
    fixed runtime output and added feature to see peak and continuous current.
    [Utilities.cpp, Utilities.h]
2022-09-30 Create Advanced users wiring and pinouts
2024-02-25 Updated to V0.25
    Confirmed zero speed fix dramatically reduces unexpected motion.
    Homing routines combined - no need for checking board version now.
    [OSSM_Config.h, Utilities.cpp]
2024-03-01 fixed issue causing over-travel at very long strokes
    In simple penetration when rapidly switching from high to low speed on long stroke there was a case that could cause the motor to travel beyond the current stroke length. Smoothing/slowing speed update slightly resolved this.
    [OSSM_Main.ino, Utilities.cpp, Utilities.h]
2024-05-10 lengthened thread on end effectors
    [OSSM - Toy mount - Dildo mount Double Double (vac-u-loc)- 24mm threaded.stl, OSSM hold random object on 24mm thread.stl]
